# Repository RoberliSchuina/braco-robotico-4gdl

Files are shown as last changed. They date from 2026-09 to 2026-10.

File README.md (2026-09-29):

# Braço Robótico 4 GDL — Sistemas Embarcados (FAESA, 2026/2)

| Entrega | Onde está |
|---|---|
| Lista de componentes | `relatorio/Relatorio_Braco_Robotico.docx` (seção 4) |
| Peças 3D (uma por arquivo) + STL | `STL/01_…11_*.stl` (09 = suporte dos joysticks; 10/11 = garra alternativa em V) — importar cada uma em um projeto do Tinkercad (Importar → STL) |
| Protótipo montado | `STL/montagem_completa.stl`, `imagens/montagem_*.png` |
| Código Arduino IDE | `firmware/braco_robotico/braco_robotico.ino` (placa UNO; libs Servo + EEPROM) |
| Esquema elétrico | `imagens/esquema_eletrico.png` |
| Guia de ligações furo a furo (protoboard) | `Circuito_Braco_Robotico.html` (autocontido; abrir no navegador ou imprimir) |
| Lista de parafusos e fixadores (à parte) | `relatorio/Lista_Parafusos_Fixadores.docx` (também Apêndice C do relatório) |
| Manual de montagem passo a passo | `relatorio/Manual_Montagem.docx` |
| Memória de desenvolvimento/revisão | `CLAUDE.md` |

Impressão (Bambu Lab A1): PLA, bico 0,4 mm, camada 0,20 mm, preenchimento 15 %, 3 paredes, sem suportes, peças já orientadas nos STL (≈ 132 g, ≈ 6,6 h).

**Revisão de 2026-09-24 — estrutura em forquilha e garra horizontal.** Cada elo passou a ter duas chapas laterais simétricas em relação ao plano de rotação da base (03/04 = braço, 05/06 = antebraço), amarradas por uma travessa aparafusada; o servo trabalha entre elas e o lado oposto gira num munhão Ø9 impresso, em cisalhamento duplo. A garra foi para baixo da palma, com as engrenagens de eixo vertical: com o antebraço na horizontal as mandíbulas fecham num plano horizontal e o braço agarra o objeto pelos lados (captura na horizontal). O suporte dos joysticks ganhou berço de cantos em L e rasgos radiais, porque a furação do KY-023 não é padronizada.

**Duas opções de garra.** Opção A (peças 07/08, mandíbula plana) para objetos de faces planas — blocos, caixinhas, cartões. Opção B (peças 10/11, mandíbula em V de 95°) para cilindros e esferas: contato em 4 pontos, o objeto se auto-centra e não rola; como a garra fecha no plano horizontal, o sulco do V fica vertical e pega caneta, pilha ou frasco em pé na mesa. As duas usam a mesma engrenagem e os mesmos parafusos — a troca leva dois minutos e não muda o firmware (ver `imagens/garras.png`).

Regenerar tudo: `python cad/gerar_pecas.py && python cad/gerar_esquema.py && python relatorio/gerar_relatorio.py && python relatorio/gerar_lista_parafusos.py && python relatorio/gerar_manual_montagem.py`\nConferir a mecânica (colisões, engrenagens, envelope e torque): `python cad/verificacao.py`
(requer `pip install trimesh manifold3d shapely numpy matplotlib python-docx`).

Comando: 2 módulos joystick KY-023 (J1 = base/ombro + botão gravar/reproduzir; J2 = garra/cotovelo + botão abre/fecha garra / home). Controle incremental com zona morta; ligar com os joysticks soltos (calibração do centro).

Firmware compilado com `arduino-cli compile --fqbn arduino:avr:uno` em 2026-09-19: 11 650 bytes de flash (36 %), 451 bytes de RAM (22 %), sem avisos.

Verificação (2026-09-24, `python cad/verificacao.py`): 9 malhas estanques conferidas depois de exportadas; varredura booleana do cotovelo (palma encosta na plataforma a 148° → firmware limitado a 40..140°) e do ombro; engrenagens com interpenetração 0,0000 mm² e folga de flanco 0,190 mm; envelope medido no modelo (alcance 186 mm, altura 249 mm); torque do ombro 0,52 kgf·cm em vazio (29 % do travamento) e carga útil ≈ 20 g estendido / ≈ 65 g recolhido. A base **precisa** ser parafusada na tábua de apoio e S3/S4 precisam de extensores de cabo (BOM itens 14 e 15). Limite de operação: com o ombro além de 135° e o cotovelo dobrado, o antebraço desce abaixo do plano da mesa e toca o disco da base.

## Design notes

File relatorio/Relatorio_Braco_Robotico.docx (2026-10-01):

FAESA — CENTRO UNIVERSITÁRIO

Curso de Engenharia da Computação

Disciplina: Sistemas Embarcados — 2026/2

BRAÇO ROBÓTICO DE 4 GRAUS DE LIBERDADE

Projeto, modelagem 3D, impressão (Bambu Lab A1) e firmware em Arduino

Aluno(a): ______________________________________

Professor(a): ___________________________________

Vitória – ES

Setembro de 2026

# Sumário

(pressione F9 para atualizar)

# 1. Objetivo

Construir um braço robótico de 4 graus de liberdade (GDL) utilizando a plataforma de prototipação Arduino, cobrindo todo o ciclo de um sistema embarcado: especificação, projeto mecânico (peças modeladas em 3D e impressas na Bambu Lab A1), projeto eletrônico, firmware em Arduino IDE e testes.

Entregas exigidas pela disciplina:

1. Lista de componentes necessários (seção 4).
2. Modelo 3D de cada peça em arquivos separados, com os arquivos STL individuais para impressão (seções 5 e 6).
3. Desenho do protótipo montado (seção 7).
4. Código-fonte executado no Arduino IDE (seção 9 e Apêndice A).

Requisitos de fabricação: impressora Bambu Lab A1, altura de camada 0,2 mm e densidade de preenchimento 15 %.

# 2. Visão geral da solução

O braço é do tipo articulado (antropomórfico) com quatro juntas acionadas por micro-servos SG90/MG90S: rotação da base (S1), ombro (S2), cotovelo (S3) e garra (S4). As juntas usam o próprio horn (braço) do servo encaixado em um bolso da peça — solução simples, barata e comum em braços didáticos.

Cada elo é uma FORQUILHA: duas chapas de 4 mm, uma de cada lado do plano de rotação da base, ligadas por uma travessa aparafusada. O servo da junta fica entre as duas chapas, com o flange na chapa motriz; do lado oposto, um munhão Ø9 impresso na própria chapa gira em um mancal Ø9,4. Com isso a carga é dividida entre dois apoios (cisalhamento duplo) em vez de pendurar em balanço no eixo do servo, e o centro de massa fica sobre o eixo da base — o conjunto é simétrico e equilibrado, sem o esforço lateral que a versão anterior, em chapa única, impunha ao estriado de nylon do horn.

A garra é de duas engrenagens espelhadas (16 dentes, módulo 1,5): uma acionada pelo servo e a outra girando livre em um pino M3, o que produz abertura simétrica dos dedos. Ela é montada sob a PALMA — uma chapa transversal na ponta do antebraço, que também é a travessa dessa forquilha —, com os eixos das engrenagens ao longo do eixo X do antebraço. Com o antebraço na horizontal esses eixos ficam VERTICAIS e as mandíbulas fecham num plano horizontal: o braço se aproxima de lado e agarra pelas laterais um objeto apoiado na mesa (captura na horizontal), em vez de descer sobre ele com o antebraço apontando para baixo.

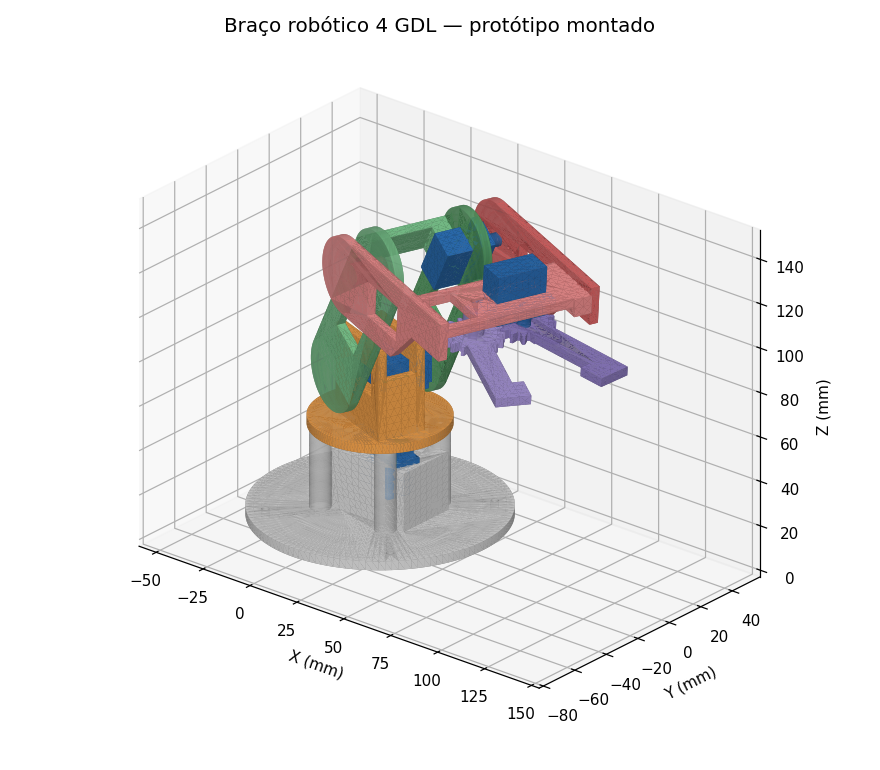
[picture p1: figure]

Figura 1 — Protótipo montado (modelo 3D gerado a partir das peças).

Item | Especificação
Graus de liberdade | 4 (base, ombro, cotovelo, garra)
Atuadores | 4 × micro-servo SG90 (plástico) ou MG90S (metálico, recomendado para ombro e cotovelo)
Controlador | Arduino UNO R3 (ATmega328P, 16 MHz)
Interface de comando | 2 módulos joystick analógico KY-023 (4 eixos + 2 botões: gravar/reproduzir poses, voltar à posição de referência, abrir/fechar garra) + terminal serial
Estrutura dos elos | Forquilha simétrica: 2 chapas de 4 mm por elo (motriz + livre), vão de 37,6 mm no braço e 67,2 mm no antebraço; pivô livre em munhão Ø9 impresso
Comprimento dos elos | Braço 70 mm (ombro→cotovelo); antebraço 62 mm (cotovelo→eixo da garra); dedos 55 mm
Plano de fechamento da garra | Horizontal — engrenagens com eixo vertical quando o antebraço está na horizontal; as mandíbulas ficam 2,8 mm abaixo do eixo do antebraço e 39 mm à frente da ponta das chapas
Alcance horizontal máx. | ≈ 186 mm a partir do eixo da base (ombro em 165°, cotovelo quase esticado); altura do ombro 68,8 mm; altura máxima da ponta dos dedos ≈ 249 mm
Opções de garra | Duas ferramentas intercambiáveis: A (mandíbula plana, objetos prismáticos) e B (mandíbula em V, auto-centrante para cilindros e esferas em pé) — ver seção 5.6
Abertura da garra | 0 mm (mandíbulas encostadas, S4 = 73°) a ≈ 57 mm na raiz / 71 mm nas pontas (S4 = 110°)
Carga útil estimada | ≈ 20 g com o braço estendido (186 mm) e ≈ 65 g com o braço recolhido (vertical), mantendo o ombro em ≤ 50 % do torque de travamento (1,8 kgf·cm a 5 V); ≈ 30 g aceitando 60 %
Alimentação | Fonte chaveada 5 V / 5 A para os servos (mínimo aceitável 3 A — ver seção 8.1); Arduino pelo USB OU pela mesma fonte (nunca os dois ao mesmo tempo); GND comum
Material / massa impressa | PLA, ≈ 137 g no total (11 peças, incluindo o controle de mão dos joysticks)

## 2.1 Envelope de trabalho

Alturas e alcances medidos no modelo 3D montado (referência: mesa de apoio da base, eixo Z; alcance medido a partir do eixo de rotação da base). A altura máxima ocorre com o braço totalmente esticado para cima — ombro a 90° e cotovelo a 180°, dentro dos limites ANG_MIN/ANG_MAX do firmware.

Referência (braço esticado para cima) | Altura (mm)
Topo da torre da base (apoio do servo S1) | 30,0
Eixo do ombro (S2) | 68,8
Eixo do cotovelo (S3), braço vertical | 138,8
Eixo da garra (S4), antebraço vertical (referência geométrica) | 200,8
Ponta dos dedos — altura máxima medida no modelo (cotovelo em 20°) | 249,1

Pose | Ângulos (ombro / cotovelo) | Altura máx. (mm) | Alcance horizontal (mm)
Esticado para cima (altura máxima) | 90° / 20° (limite ANG_MIN do cotovelo) | 249 | 53
Repouso — home | 90° / 90° | 165 | 119
Alcance horizontal máximo | 165° (limite ANG_MAX do ombro) / 20° | 108 | 186

Valores medidos diretamente no modelo 3D (cad/verificacao.py). Como a estrutura agora é simétrica, o centro da garra fica no PLANO do braço — não há mais o deslocamento lateral de ≈ 34 mm da versão em chapa única, e o alcance vale igualmente para os dois lados.

Limite de operação (não é limite de software): com o ombro além de ≈ 135° e o cotovelo dobrado além de ≈ 140°, o antebraço desce abaixo do plano da mesa e chega a tocar o disco da base (interferência medida: 0,1 a 1,5 cm³ nas poses extremas; com o ombro em 165° a garra chega a ≈ 28 mm abaixo da mesa). Não há batente mecânico: ou o operador evita a combinação, ou se reduz ANG_MAX do ombro para 135° no firmware — o que custa ≈ 50 mm de alcance.

# 3. Arquitetura do sistema embarcado

Do ponto de vista de sistemas embarcados, o projeto é um laço de controle em malha aberta a 50 Hz (mesmo período do sinal PWM dos servos, 20 ms). A cada ciclo o firmware lê os sensores (eixos e botões dos joysticks), decide o modo de operação (máquina de estados MANUAL / REPRODUZINDO) e atualiza os atuadores, limitando a velocidade de cada junta para obter movimentos suaves e reduzir picos de corrente. Como o joystick retorna ao centro por mola, o comando é incremental (controle de velocidade): a deflexão do eixo define a taxa de variação do ângulo da junta, com zona morta em torno do centro e curva quadrática para precisão em movimentos finos.

- Entradas: 2 joysticks KY-023 — 4 eixos analógicos (A0–A3, ADC 10 bits) e 2 botões (D2, D4, pull-up interno); porta serial USB (115200 bps).
- Saídas: 4 sinais PWM de servo (D3, D5, D6, D9 — biblioteca Servo.h, pulsos de 500 a 2500 µs), LED de status (D13).
- Memória: até 16 poses gravadas em RAM, com persistência opcional na EEPROM (assinatura de validação); centro de cada eixo do joystick calibrado na partida.
- Segurança: limites mínimo/máximo por junta em software (evitam colisão do antebraço com o braço), partida sequencial dos servos e posição de repouso na inicialização.

# 4. Lista de componentes (BOM)

Preços em reais são estimativas de mercado (2026) para orientar o orçamento; confirmar no momento da compra.

# | Componente | Qtd | Unit. (R$) | Total (R$) | Função / observação

1 | Arduino UNO R3 (ou compatível) + cabo USB A-B | 1 | 80 | 80 | Controlador
2 | Micro-servo MG90S (engrenagem metálica, 180°) | 2 | 28 | 56 | Ombro (S2) e cotovelo (S3) — mesmo torque do SG90 a 5 V (1,8 kgf·cm), mas engrenagens metálicas e rolamento no eixo: resistem a travamentos e ao esforço lateral
3 | Micro-servo SG90 (180°) com kit de horns e parafusos | 2 | 15 | 30 | Base (S1) e garra (S4)
4 | Módulo joystick analógico KY-023 (2 eixos + botão) | 2 | 9 | 18 | Comando manual das 4 juntas (J1: base/ombro; J2: garra/cotovelo)
5 | Cabo jumper fêmea-macho 20 cm (5 vias por joystick) | 10 | 0,4 | 4 | Ligação dos joysticks à protoboard
6 | Fonte chaveada 5 V / 5 A com plug P4 (2,1 mm, centro positivo) | 1 | 50 | 50 | Alimentação dos servos. Dimensionamento na seção 8.1: 1,85 A no pior caso de operação e 2,70 A com os 4 servos travados. Uma fonte de 3 A atende a operação normal, mas fica a 90 % do nominal em travamento
7 | Jack P4 fêmea com borne (adaptador) | 1 | 6 | 6 | Conexão da fonte na protoboard
8 | Capacitor eletrolítico 1000 µF / 16 V (+ 4 cerâmicos 100 nF) | 1 | 4 | 4 | Desacoplamento do barramento dos servos: o eletrolítico cobre o degrau de corrente até a fonte reagir (~100 µs); os cerâmicos, junto a cada conector, cortam o ruído de comutação do motor
9 | Protoboard 400 pontos | 1 | 15 | 15 | Montagem do circuito
10 | Jumpers macho-macho e macho-fêmea (kit 40 + 40) | 1 | 18 | 18 | Ligações
11 | Parafusos e fixadores — ver lista à parte (Apêndice C / Lista_Parafusos_Fixadores.docx) | 1 | 41 | 41 | PA 2,0×8, PA 1,7×6, M3×25 inox + nylock, M3×12 + porcas/arruelas, M3×16, espaçadores
12 | Filamento PLA 1,75 mm (≈ 137 g usados, já com as duas opções de garra) | 1 | 13 | 13 | Custo proporcional do carretel (R$ 90 / kg)
13 | Abraçadeiras de nylon 2,5 × 100 mm + fita dupla-face | 1 | 6 | 6 | Cabos nos elos e no suporte dos joysticks / fixação da base
14 | Base de MDF ou acrílico 200 × 150 × 6 mm (OBRIGATÓRIA) | 1 | 10 | 10 | Fixação da base fixa (4 furos Ø3,4): o disco Ø110 solto tomba com ≈ 15 g na garra em extensão máxima
15 | Cabo extensor de servo, 3 vias, 300 mm (padrão JR/Futaba) | 2 | 4 | 8 | S3 (cotovelo) e S4 (garra): o cabo de fábrica (≈ 250 mm) não chega ao circuito passando pelos elos

Custo total estimado: R$ 359.

Os parafusos, porcas e arruelas estão dimensionados item a item (furo, empilhamento, modelo e material) na lista à parte do Apêndice C, também entregue como documento separado (relatorio/Lista_Parafusos_Fixadores.docx).

Ferramentas: chave Phillips PH0/PH1, chave de boca 5,5 mm, alicate de corte, estilete (rebarbas), ferro de solda (opcional), paquímetro.

# 5. Projeto mecânico e modelagem 3D

## 5.1 Método de modelagem

As peças foram projetadas de forma paramétrica por geometria construtiva de sólidos (CSG) — união e subtração de primitivas (caixas e cilindros), exatamente a lógica de trabalho do Tinkercad (sólidos e furos). O script cad/gerar_pecas.py contém todas as cotas e gera um STL por peça, já na orientação de impressão; a seção 6 descreve como reproduzir/importar cada peça no Tinkercad em um projeto separado.

## 5.2 Peças

Arquivo STL | Peça | Função | Dimensões (mm) | Massa est. | Tempo est.
01_base_fixa.stl | Base fixa | Apoio do braço; abriga o servo S1 (rotação da base) | 110.0 × 110.0 × 40.3 | 40.7 g | 122 min
02_plataforma_giratoria.stl | Plataforma giratória | Fixa no horn de S1; forquilha do ombro (parede motriz de S2 + parede do mancal) | 60.0 × 60.0 × 44.0 | 15.0 g | 45 min
03_braco_motriz.stl | Braço — chapa motriz | Lado acionado do elo superior: horn de S2 e servo S3 | 34.0 × 104.0 × 4.0 | 6.4 g | 19 min
04_braco_livre.stl | Braço — chapa livre | Lado livre do elo superior: munhão do ombro, mancal do cotovelo e travessa | 34.0 × 104.0 × 41.6 | 9.5 g | 29 min
05_antebraco_motriz.stl | Antebraço — chapa motriz | Lado acionado do elo inferior: horn de S3 | 34.0 × 95.0 × 4.0 | 5.6 g | 17 min
06_antebraco_livre.stl | Antebraço — chapa livre + palma | Lado livre do elo inferior e base da garra (servo S4 e pino do dedo livre) | 34.0 × 96.0 × 71.2 | 11.0 g | 33 min
07_garra_dedo_motriz.stl | Dedo motriz da garra | Engrenagem acionada pelo horn de S4 + dedo | 26.4 × 68.2 × 4.0 | 2.3 g | 7 min
08_garra_dedo_livre.stl | Dedo livre da garra | Engrenagem espelhada que gira no pino M3 + dedo | 26.1 × 68.0 × 14.8 | 2.9 g | 9 min
09_suporte_joysticks.stl | Suporte dos joysticks | Controle de mão: berço dos 2 módulos KY-023 (4 rasgos M3 cada) | 160.0 × 100.0 × 9.2 | 38.2 g | 115 min
10_garra_v_dedo_motriz.stl | Dedo motriz da garra em V (opção B) | Alternativa ao 07: mandíbula com entalhe em V que auto-centra cilindros e esferas | 26.4 × 68.2 × 4.0 | 2.3 g | 7 min
11_garra_v_dedo_livre.stl | Dedo livre da garra em V (opção B) | Alternativa ao 08: mesma engrenagem espelhada, com o entalhe em V | 26.1 × 68.0 × 14.8 | 2.9 g | 9 min

Total estimado: ≈ 137 g de PLA e ≈ 6.9 h de impressão (0,2 mm, 15 %). As peças cabem na mesa de 256 × 256 mm da A1 em uma ou duas chapas (o Bambu Studio arranja automaticamente; a base Ø110 e o suporte 160 × 100 não podem ficar lado a lado no mesmo eixo).

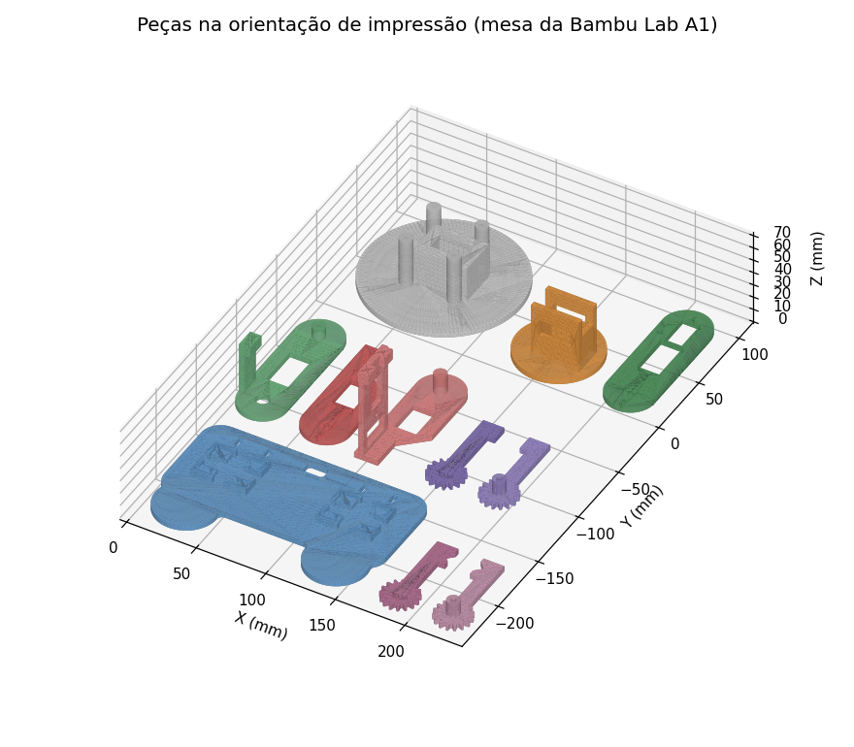
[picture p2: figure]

Figura 2 — As onze peças na orientação de impressão (como devem ficar na mesa): as travessas e a palma são impressas em pé sobre as chapas deitadas.

## 5.3 Interfaces com o servo SG90/MG90S (cotas adotadas)

Elemento | Cota adotada | Justificativa
Rasgo do corpo do servo | 23,2 × 12,6 mm (corpo 22,8 × 12,2) | Folga de 0,2 mm por lado para FDM a 0,2 mm
Furos do flange | Ø1,7 mm, 27,5 mm entre centros | Furo-piloto a 85 % do Ø2,0 do parafuso autoatarraxante do kit do servo
Posição do eixo | Deslocado 5,3 mm do centro do corpo | O eixo do SG90 fica a 6,1 mm da extremidade
Bolso do horn | Cubo Ø9,2; braços em tronco de cone de 9,2 mm (junto ao cubo) a 5,4 mm (ponta); 2,0 mm de profundidade | O braço do horn do SG90 sai tangente ao cubo Ø8 e afina até a ponta — um rasgo reto deixaria o horn sem assentar. Horn de 2 braços (elos), em cruz (plataforma) e simples (garra)
Furo do parafuso central | Ø2,6 mm passante | Parafuso PA 2,0 × 6 + arruela M2 atravessa 2 mm de chapa e o topo do horn e rosqueia ≈ 3 mm no furo cego do eixo (medir a profundidade do furo antes: ver lista de fixadores)
Furos-piloto do horn | Ø1,5 mm | Micro parafusos autoatarraxantes PA 1,7 × 6 (não vêm no kit do servo)
Pino da engrenagem livre | Ø3,4 mm (chapa) / Ø3,4 mm (engrenagem) | Parafuso M3 × 25 inox como eixo + porca autotravante
Engrenagens da garra | 16 dentes, módulo 1,5, Ø primitivo 24 (= distância entre centros), Ø externo 26,4 (addendum 0,8 m); folga de flanco 0,19 mm | Dentes trapezoidais com addendum encurtado: sem interferência de topo; a folga (≈ 1,6° de backlash) absorve a imprecisão do FDM
Munhão / mancal (lado livre) | Munhão Ø9 impresso (8,8 mm no ombro, 14,8 mm no cotovelo) em mancal Ø9,4 passante | Folga diametral de 0,4 mm — gira livre depois de tirar a rebarba. Não leva parafuso: quem prende axialmente é o parafuso central do horn do lado motriz somado à travessa
Travessa do braço / palma do antebraço | 2 furos passantes Ø3,4 na chapa motriz + furo-piloto Ø2,5 × 8 mm no reforço; parafusos M3 × 10 | Amarram as duas chapas de cada elo (fecham a forquilha). Sem elas as chapas abrem sob esforço lateral e o munhão sai do mancal
Espessura das chapas | 4 mm (≈ 20 camadas de 0,2 mm) | Rigidez adequada com 15 % de preenchimento

## 5.4 Análise simplificada de carga

O servo mais solicitado é o ombro (S2). O cálculo é um diagrama de corpo livre feito sobre o próprio modelo 3D (cad/verificacao.py soma massa × braço de alavanca peça por peça, usando o centro de massa de cada malha e 13,4 g por MG90S e 9 g por SG90). Na pior pose — braço e antebraço na horizontal, alcance máximo — dá τ_S2 = 0,52 kgf·cm sem carga (29 % do travamento) e τ_S2 ≈ 0,52 + 0,018·m [kgf·cm, m em gramas] com uma massa m na ponta. A 5 V, SG90 e MG90S entregam o mesmo torque de travamento, ≈ 1,8 kgf·cm (os 2,2 kgf·cm do MG90S são a 6 V).

Um servo de hobby não deve sustentar pose acima de ≈ 50 % do travamento: com 25 g o ombro vai a 54 % e com 50 g a 79 % (aquece e perde posição). Daí a carga útil de ≈ 20 g em extensão máxima — ou ≈ 30 g aceitando 60 % do travamento em movimentos curtos. Com o braço recolhido (vertical) o braço de alavanca cai para o antebraço apenas e a carga útil sobe para ≈ 65 g. O cotovelo (S3) fica em 39 % mesmo com 50 g e a garra tem força de sobra (≈ 3,6 N de travamento na mandíbula).

Comparação com a versão anterior, em chapa única: duplicar as chapas levou a massa móvel de ≈ 39 g para ≈ 59 g e o torque em vazio de 0,39 para 0,52 kgf·cm, custando ≈ 5 g de carga útil. Em troca, cada junta passou a trabalhar em cisalhamento duplo (dois apoios em vez de um balanço), o esforço lateral sobre o estriado de nylon do horn praticamente desapareceu e o centro de massa ficou sobre o eixo da base — o que também alivia S1. As janelas nas quatro chapas e na palma foram dimensionadas para recuperar parte dessa massa. O MG90S é indicado nas juntas 2 e 3 não pelo torque, mas pelas engrenagens metálicas e pelo rolamento do eixo. Ponto fraco remanescente: o conjunto girante pendura no eixo de S1 sem mancal — por isso a base tem quatro colunas de encosto a 0,5 mm da plataforma, que limitam o balanço sem travar o giro.

## 5.5 Suporte dos joysticks (controle de mão)

Os dois módulos KY-023 são montados em uma placa impressa no formato de controle de videogame (160 × 100 × 9,2 mm, arquivo 09_suporte_joysticks.stl), inspirada nos suportes de MDF cortados a laser. Joystick 1 (esquerda) comanda base e ombro; joystick 2 (direita), garra e cotovelo — mesma lógica de um controle de videogame.

Fixação — por que não é por furo: a placa do KY-023 mede 34 × 26 mm (valor confirmado nas fichas do fabricante e de distribuidores), mas NENHUM datasheet publica a distância entre os furos Ø3, e ela varia de fabricante para fabricante; além disso o gimbal do joystick (≈ 22 × 22 mm) encosta nos furos do lado estreito em vários clones. Por isso o suporte não depende dessa cota:

- Berço de 4 cantos em L: posiciona o módulo pela BORDA da placa (envelope 34,6 × 26,6 mm), com assento de 3 mm que afasta as soldas da chapa e lábio de 2,2 mm que trava a placa lateralmente.
- 4 rasgos radiais 3,4 × 11,4 mm: o parafuso M3 corre 8 mm na direção radial, de modo que a mesma peça aceita qualquer furação simétrica entre ≈ 21,5 × 15,4 mm e ≈ 34,5 × 24,6 mm (o nominal adotado é 28 × 20 mm). Medir a placa com paquímetro só é necessário se ela estiver fora dessa faixa — aí basta alterar JOY_FUROS no script.
- Parafusos M3 × 12 + arruela ampla Ø9 + porca: 2 a 4 por módulo, conforme os furos acessíveis na placa. Se o gimbal cobrir dois deles, os cantos do berço já impedem o módulo de sair de posição.

Acima de cada módulo há dois rasgos para abraçadeira de nylon, que prendem o chicote de 5 fios (barra de pinos voltada para cima), e no topo um rasgo para pendurar o controle.

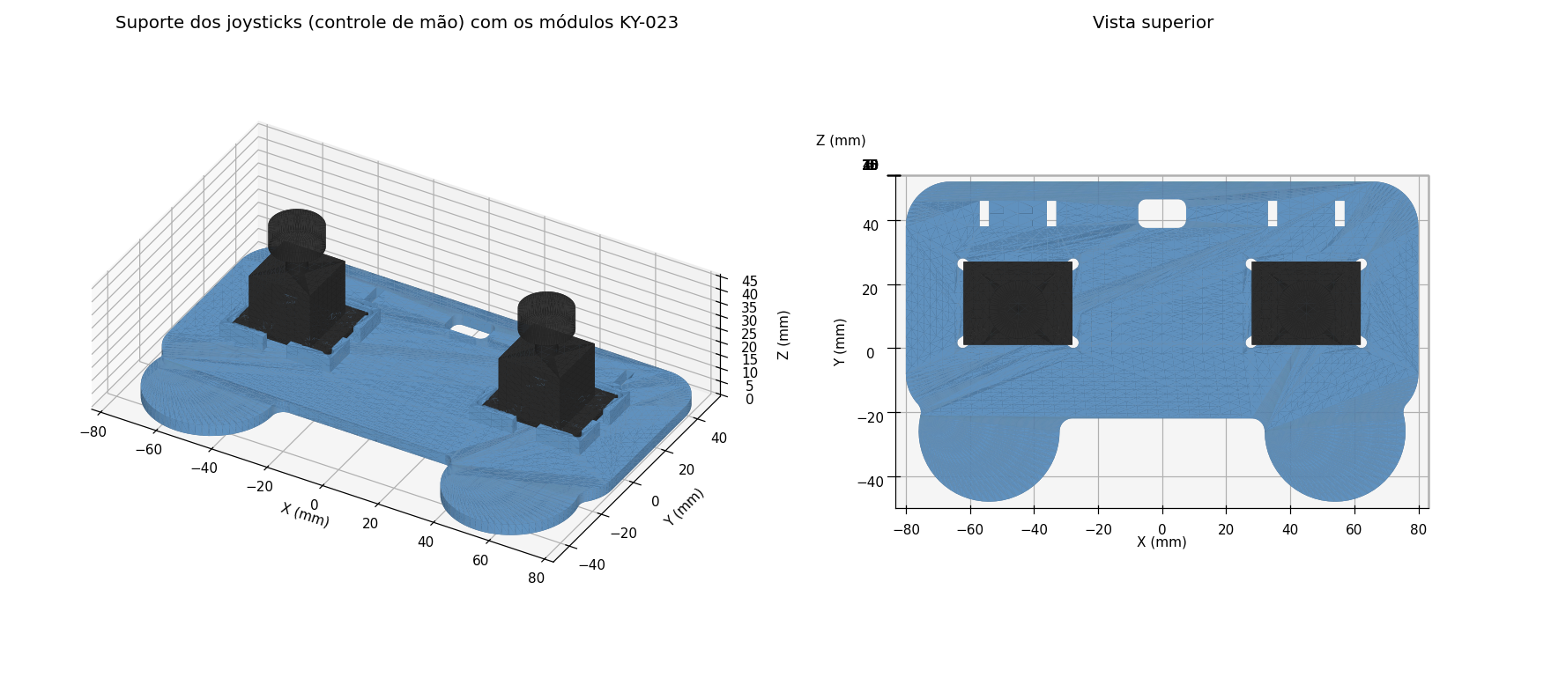
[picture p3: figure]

Figura 3 — Suporte dos joysticks: berço de cantos em L e rasgos radiais, com os dois módulos KY-023 posicionados.

## 5.6 Duas opções de garra (ferramenta intercambiável)

A garra é a interface com o objeto, e nenhuma geometria serve para tudo. O projeto entrega dois pares de dedos que usam a MESMA engrenagem, o mesmo bolso de horn, o mesmo pino M3 e a mesma distância entre centros — ou seja, são troca direta, sem alterar antebraço, palma, servo ou firmware:

- Opção A — mandíbula plana (07 e 08): faces retas de 10 × 12 mm. Contato em 2 pontos, ideal para objetos de faces planas e paralelas: blocos, caixinhas, cartões, peças prismáticas. É a garra montada nas figuras deste relatório.
- Opção B — mandíbula em V (10 e 11): faces de 10 × 17 mm com entalhe em V de ≈ 95° (apex 5 mm dentro da face, abertura 11 mm). Contato em 4 pontos: o objeto se auto-centra e não rola nem escapa. Como a garra fecha no plano horizontal, o sulco do V fica VERTICAL — é a opção para pegar cilindros e esferas em pé sobre a mesa: canetas, marcadores, pilhas, tubos de ensaio, frascos, bolinhas.

Capacidade medida no modelo (maior cilindro em pé que as duas mandíbulas tocam ao mesmo tempo, em função do ângulo do servo da garra; 75° = dedos paralelos, 110° = ANG_MAX):

Ângulo de S4 | 75° (dedos paralelos) | 80° | 90° | 100° | 110° (aberta)
Opção A — plana | Ø 4 mm | Ø 13 mm | Ø 29 mm | Ø 44 mm | Ø 58 mm
Opção B — em V | Ø 10 mm | Ø 15 mm | Ø 28 mm | Ø 41 mm | Ø 53 mm

Perto do fechamento a diferença é grande: com os dedos quase paralelos a opção A só consegue prender uma lâmina de 4 mm, enquanto o V já abraça um cilindro de 10 mm. Na abertura máxima as duas são equivalentes (o V “gasta” 5 mm de cada mandíbula). Em ambas, o ângulo em que as mandíbulas se tocam é o mesmo (73° no servo), então GARRA_FECHADA e ANG_MIN[3] do firmware não mudam com a troca.

Troca da garra (2 minutos): soltar o parafuso central do horn de S4 e o parafuso M3 × 25 do dedo livre, retirar os dois dedos, montar o outro par na mesma ordem da seção 7.1 (S4 em 75°, dedos paralelos) e reapertar. O horn continua no dedo motriz de cada par — quem imprimir as duas opções pode deixar um horn em cada uma e a troca fica ainda mais rápida (o kit do servo traz vários horns).

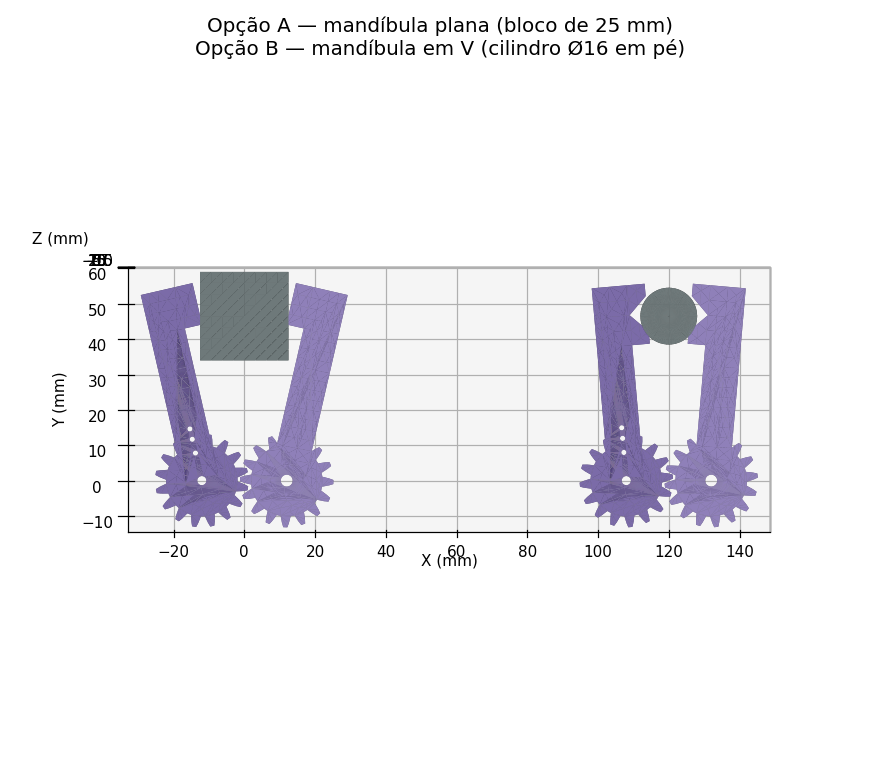
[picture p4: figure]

Figura 4 — As duas opções de garra vistas pelo eixo das engrenagens: à esquerda a mandíbula plana com um bloco de 25 mm; à direita a mandíbula em V com um cilindro Ø16 em pé.

# 6. Modelagem no Tinkercad e geração dos STL

## 6.1 Importar os STL prontos (um projeto por peça)

5. Acesse https://www.tinkercad.com/dashboard e clique em Criar → Projeto 3D.
6. Clique em Importar (canto superior direito) → selecione STL/01_base_fixa.stl → unidade: milímetros → escala 100 %.
7. Renomeie o projeto (ex.: “Braço 4GDL – 01 Base fixa”). Repita para as outras oito peças, cada uma em um projeto separado.
8. Para o protótipo montado, importe STL/montagem_completa.stl em um décimo projeto (visualização).
9. Exportar: Exportar → .STL (o Tinkercad gera um STL individual por projeto). Esses arquivos vão para o Bambu Studio.

## 6.2 Receita para modelar cada peça com primitivas do Tinkercad

Caso se deseje construir as peças do zero no Tinkercad (sólidos = formas; furos = formas marcadas como “Furo”; alinhar e agrupar), as cotas abaixo reproduzem o modelo. Origem: centro da peça; Z para cima.

01 Base fixa

- Sólidos: Cilindro Ø110 × 4; Caixa 38,6 × 28 × 27 (torre) apoiada em z=3, centro em x=+5,3; 4 Cilindros Ø9 × 36,3 (colunas de encosto) em raio 24,5 (45°, 135°, 225°, 315°), de z=4 a z=40,3.
- Furos: Caixa 28 × 18 × 28 (cavidade, centro x=+5,3, de z=−1 a 27); Caixa 8 × 60 × 2 (canal do cabo, sob a base, x −4..4, y 0..60); Caixa 23,2 × 12,6 (rasgo do servo na tampa, centro x=+5,3); 2 Cilindros Ø1,7 em x=−8,45 e x=+19,05; 4 Cilindros Ø3,4 em raio 47 (45°, 135°, 225°, 315°).

02 Plataforma giratória

- Sólidos: Cilindro Ø60 × 4; DUAS Caixas 34,6 × 4 × 41 (paredes da forquilha: uma em y 4..8, outra em y −14..−10; z 3..44; centro x=+5,3); 2 Caixas 4 × 14,5 × 27 (nervuras que ligam as duas paredes, em x −12..−8 e 18,6..22,6; y −10..4,5; z 3..30).
- Furos: bolso em cruz na face inferior (Cilindro Ø9,2 × 2 + 4 braços de 14 mm em tronco de cone Ø9,2→Ø5,4, profundidade 2); Cilindro Ø2,6 passante no centro; 8 Cilindros Ø1,5 (±7,5 e ±11 nos dois eixos); rasgo 23,2 × 12,6 na parede motriz (centro x=+5,3, z=28) + 2 Cilindros Ø1,7 em x=−8,45 e +19,05 (z=28); Cilindro Ø9,4 passante na parede livre em (0; z=28) — é o mancal do munhão do braço.

03 Braço — chapa motriz

- Sólidos: Caixa 34 × 4 × 70 + 2 Cilindros Ø34 × 4 (eixo Y) em z=0 e z=70 (chapa no plano XZ).
- Furos: janela 16 × 30 (z 22..52); bolso duplo na face interna (Cilindro Ø9,2 × 2 + 2 braços de 16,5 mm em tronco de cone Ø9,2→Ø5,4); Cilindro Ø2,6 passante em z=0; 4 furos Ø1,5 em z=±8 e ±12; rasgo 12,6 (x) × 23,2 (z) centrado em (0; 64,7) [eixo do servo em z=70]; furos Ø1,7 em z=50,95 e z=78,45; 2 furos Ø3,4 em (−13; 59) e (−13; 67) para os parafusos da travessa.

04 Braço — chapa livre

- Sólidos: mesma silhueta da chapa motriz; Cilindro Ø9 × 9,8 saindo da face interna em z=0 (munhão do ombro); Caixa 4 × 38,6 × 14 (travessa: x −17..−13, y −1..37,6, z 56..70); Caixa 8 × 8 × 14 (reforço dos furos-piloto, x −17..−9, y 29,6..37,6).
- Furos: janela 16 × 30 (z 22..52); Cilindro Ø9,4 passante em z=70 (mancal do cotovelo); 2 furos-piloto Ø2,5 × 8,4 na face livre do reforço, em (−13; 59) e (−13; 67).

05 Antebraço — chapa motriz

- Sólidos: Cilindro Ø34 × 4 em z=0; Caixa 34 × 4 × 40; a partir de z=40 a borda inferior recua em diagonal até x=0 em z=56 e segue reta até a ponta (z=78), para deixar as mandíbulas livres.
- Furos: janela 16 × 24 (z 20..44); bolso duplo + Ø2,6 + 4 furos Ø1,5 como no braço; 2 furos Ø3,4 em (−10; 54) e (−10; 74) para os parafusos da palma.

06 Antebraço — chapa livre + palma

- Sólidos: mesma silhueta da chapa motriz; Cilindro Ø9 × 15,8 na face interna em z=0 (munhão do cotovelo); Caixa 4 × 68,2 × 30 (PALMA: x −14..−10, y −1..67,2, z 48..78); 2 Caixas 8 × 8 × 10 (reforços dos furos-piloto na ponta da palma).
- Furos: janela 16 × 24; na palma, rasgo 23,2 × 12,6 do servo S4 (eixo em y=45,6 medido da face interna, z=62; corpo ao longo de −y) + 2 Cilindros Ø1,7 em y=26,55 e y=54,05; Cilindro Ø3,4 em (y=21,6; z=62) — pino do dedo livre; janela 13 × 22 na palma (y 3..16, z 52..74); 2 furos-piloto Ø2,5 × 8,4 em (−10; 54) e (−10; 74).

07 Dedo motriz

- Sólidos: Engrenagem (Geradores de forma → Gear): 16 dentes, módulo 1,5, Ø externo 26,4 (addendum 1,2 mm), altura 4; Caixa 10 × 55 × 4 (haste, y 0..55); Caixa 10 × 12 × 4 (mandíbula, x 0..10, y 43..55).
- Furos: bolso simples na face superior (Cilindro Ø9,2 × 2 + 1 braço de 18 mm em tronco de cone Ø9,2→Ø5,4); Cilindro Ø2,6 passante; 3 furos Ø1,5 em y=8, 12 e 15.

08 Dedo livre

- Espelho do dedo motriz (mandíbula em x −10..0), sem bolso do horn; engrenagem girada 11,25° (meio dente).
- Sólido extra: Cilindro Ø9 × 10,8 sobre a engrenagem (espaçador). Furo: Cilindro Ø3,4 passante.

10 e 11 — Dedos da garra em V (opção B)

- Iguais aos dedos 07 e 08, com duas diferenças: a mandíbula vai de y=38 a y=55 (em vez de y=43..55) e recebe um furo em forma de cunha.
- Furo: Triângulo (prisma de 4 mm de altura) com vértices (±10,5; 41), (±10,5; 52) e (±5; 46,5) — apex 5 mm dentro da face de trabalho, abertura de 11 mm. No Tinkercad: forma “Wedge”/“Roof” girada, ou um cilindro de 3 lados achatado, marcado como Furo.

09 Suporte dos joysticks

- Sólidos: Caixa 160 × 74 × 4 com cantos R14 (corpo, y −22..52); 2 Cilindros Ø44 × 4 em (±54; −26) (empunhaduras); por módulo (centros em (±45; 14)), 4 cantos em L alinhados com a borda da placa (envelope 34,6 × 26,6): assento 11 × 8 × 3 mm sob cada canto + 2 paredinhas de 2,5 mm de espessura e 5,2 mm de altura.
- Furos: 4 rasgos radiais por módulo (Caixa 3,4 × 8 com pontas redondas, apontando do centro do módulo para o furo nominal em ±14; ±10); 4 Caixas 3 × 8 em (±33..36; 38..46) e (±54..57; 38..46) (abraçadeiras); rasgo de pendurar 15 × 9 com pontas redondas centrado em (0; 42).

# 7. Protótipo montado

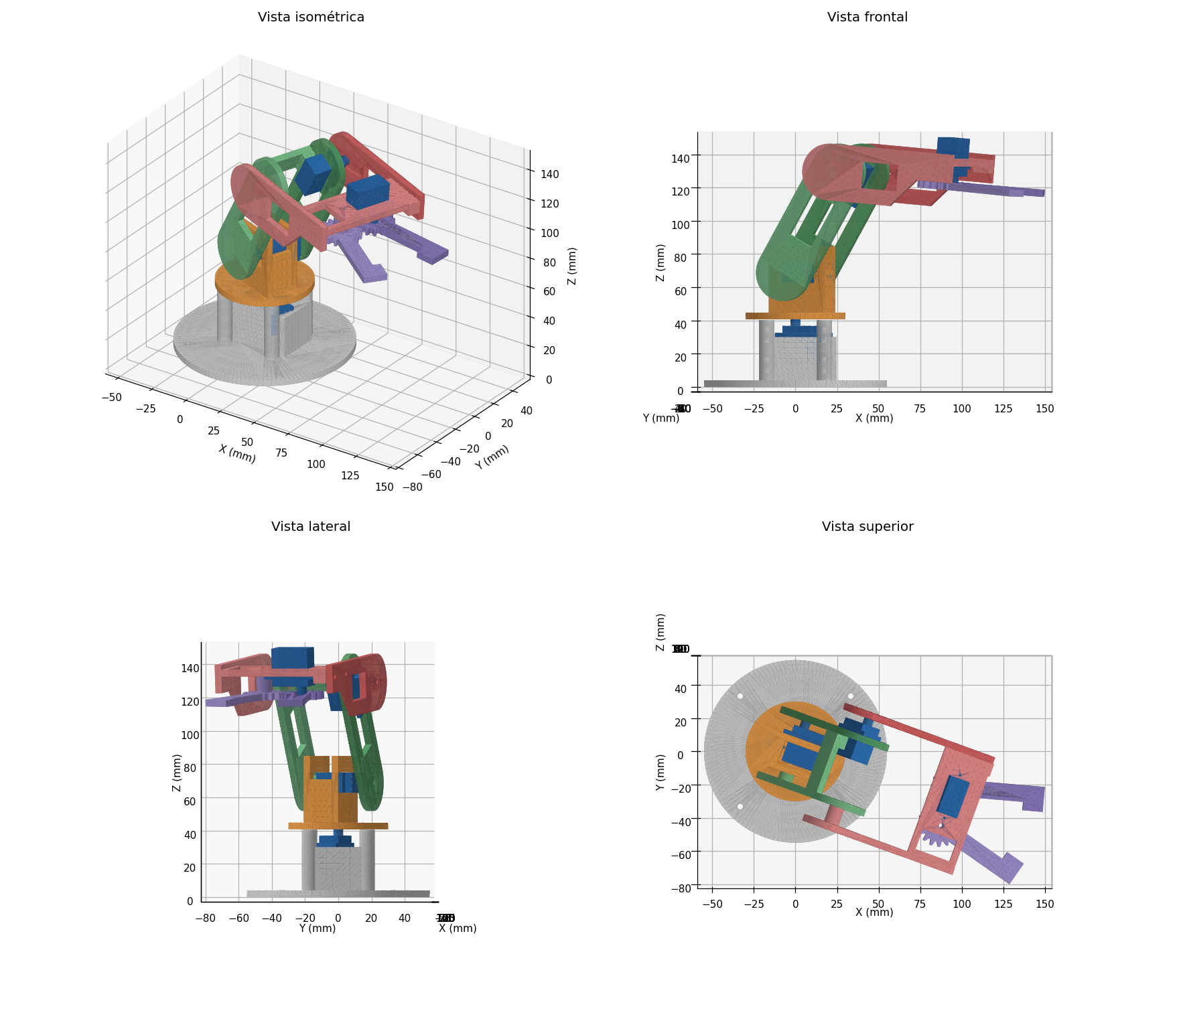
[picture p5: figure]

Figura 5 — Vistas isométrica, frontal, lateral e superior do protótipo montado (servos em azul).

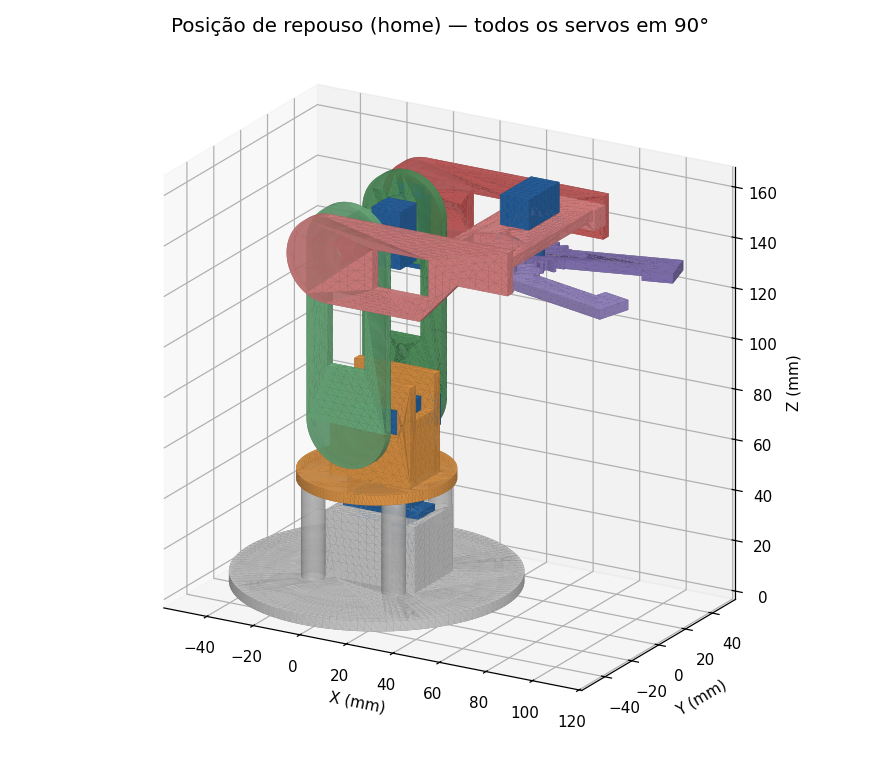
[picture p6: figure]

Figura 6 — Posição de repouso (home): todos os servos em 90°.

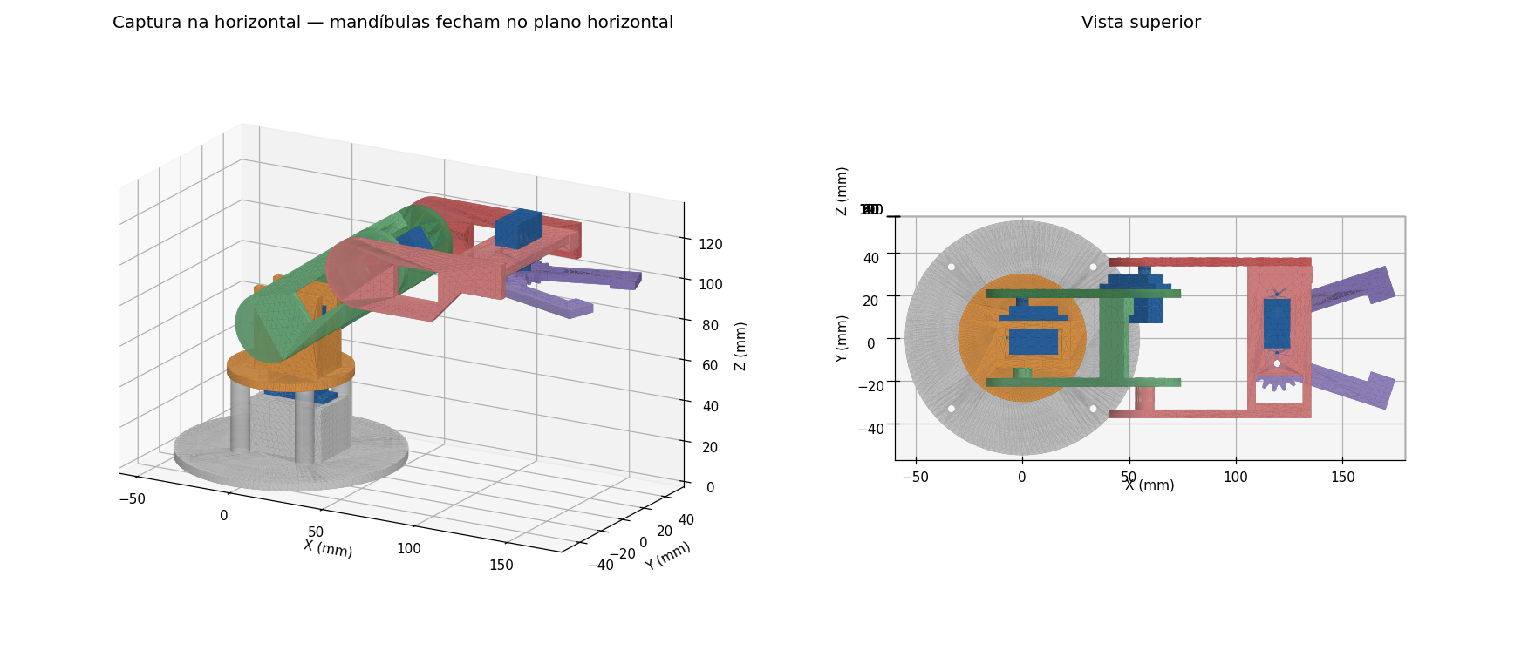
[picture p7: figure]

Figura 7 — Captura na horizontal: com o antebraço na horizontal, os eixos das engrenagens ficam verticais e as mandíbulas fecham no plano horizontal (vista superior à direita).

## 7.1 Sequência de montagem

10. Remover rebarbas; testar o encaixe de cada servo nos rasgos (deve entrar justo, sem forçar) e de cada munhão Ø9 no seu mancal Ø9,4 (deve girar livre; se prender, lixar o munhão, nunca o furo). Rosquear um parafuso PA 2,0 no furo cego do eixo de cada servo, sem peça, e medir com paquímetro quanto entra: define o comprimento do parafuso central (lista de fixadores, item 1b).
11. Base fixa: parafusar o disco na tábua de apoio (4 × M3 × 16 nos furos Ø3,4 — obrigatório, o braço estendido tomba sem isso); encaixar S1 por cima na torre (flange apoiado na tampa) e fixar com 2 parafusos PA 2,0 × 8 (do kit do servo).
12. Ligar o Arduino, carregar o firmware e enviar 's 0 90', 's 1 90', 's 2 90', 's 3 75' para centralizar os servos antes de montar os horns.
13. Plataforma: colocar o horn em cruz no bolso inferior (deve assentar no fundo; 4 micro parafusos PA 1,7 × 6), encaixar no eixo de S1 com a plataforma a 0,5 mm das colunas de encosto e fixar com o parafuso central (PA 2,0 × 6 + arruela M2). O estriado do eixo tem ≈ 21 dentes (≈ 17° por dente): escolher a posição mais próxima do alinhamento e corrigir o resto na calibração.
14. Fixar S2 na parede MOTRIZ da plataforma (a de y = 4..8): o corpo atravessa a parede para dentro da forquilha e o flange fica na face externa. Conferir que a extremidade do corpo do servo não encosta na parede livre (folga de projeto: 2,1 mm).
15. Braço: montar o horn duplo no bolso da chapa motriz (03). Encaixar primeiro a chapa LIVRE (04) — o munhão entra no mancal da parede livre —, depois a chapa motriz no eixo de S2, na vertical, e apertar o parafuso central. Fechar a forquilha aparafusando a travessa da chapa livre na chapa motriz (2 × M3 × 10, por fora da chapa motriz).
16. Fixar S3 na chapa motriz do braço (flange na face externa, corpo para dentro da forquilha).
17. Antebraço: montar o horn duplo no bolso da chapa motriz (05). Encaixar a chapa LIVRE (06, a que traz a palma) pelo munhão no mancal da chapa livre do braço; encaixar a chapa motriz no eixo de S3 a 90° do braço e apertar o parafuso central. Fechar a forquilha aparafusando a palma na chapa motriz (2 × M3 × 10).
18. Garra: aparafusar S4 na palma pelo lado de baixo (flange contra a face interna da palma, corpo atravessando para cima; 2 × PA 2,0 × 8) ANTES de montar as engrenagens — um dos furos do flange fica sob a engrenagem motriz.
19. Dedo livre: parafuso M3 × 25 de cima para baixo pela palma, arruela de nylon, dedo (espaçador Ø9 contra a palma), arruela e porca autotravante — apertar só até girar livre.
20. Dedo motriz: horn simples no bolso; com S4 em 75° encaixar a engrenagem já engrenada com o dedo livre e os dois dedos paralelos; parafuso central. Conferir que as duas mandíbulas fecham no plano horizontal quando o antebraço está na horizontal.
21. Ligar os extensores de 300 mm em S3 e S4 e passar os cabos ao longo dos elos (abraçadeiras), com uma laçada de folga em cada junta; S2 e S1 alcançam o circuito com o cabo de fábrica.
22. Garra alternativa (opção B, peças 10 e 11): se quiser trocar o par de dedos, repetir os dois passos anteriores com os dedos em V — mesma ordem, mesmo parafuso M3 × 25 e mesmo ângulo de montagem (S4 em 75°, dedos paralelos).
23. Controle de mão: assentar cada módulo KY-023 no berço (a placa encosta nos 4 cantos em L), parafusar com M3 × 12 + arruela ampla + porca nos rasgos radiais que coincidirem com os furos da placa (2 são suficientes se o gimbal cobrir os outros), com a barra de pinos voltada para cima; prender os chicotes nos rasgos com abraçadeiras e ligar à protoboard conforme o esquema.

# 8. Projeto eletrônico

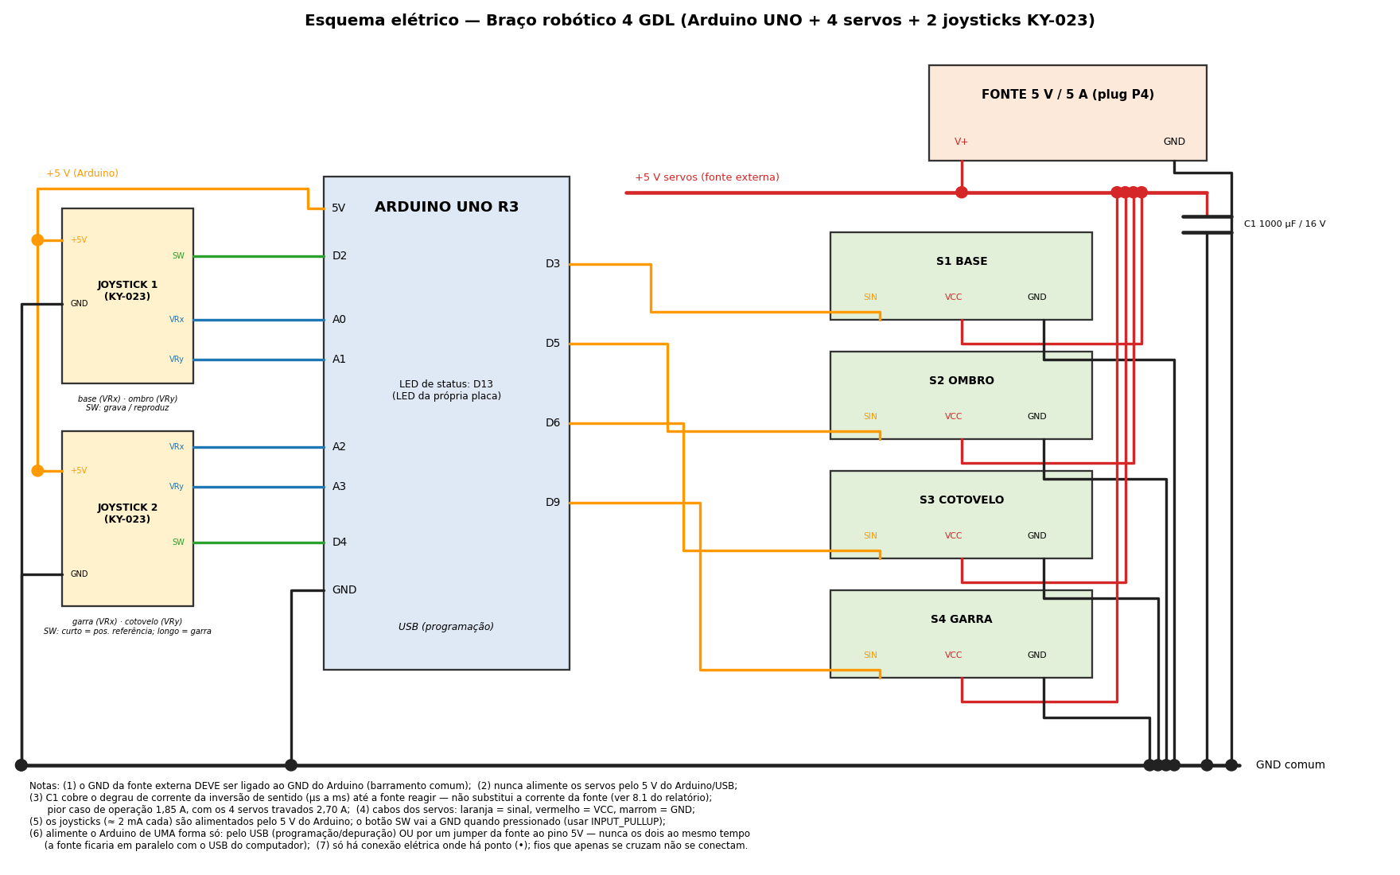
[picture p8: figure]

Figura 8 — Esquema elétrico de ligação.

Sinal | Pino Arduino | Componente | Observação
PWM servo base (S1) | D3 | SG90 — fio laranja | Servo.h, 600–2400 µs
PWM servo ombro (S2) | D5 | MG90S — fio laranja
PWM servo cotovelo (S3) | D6 | MG90S — fio laranja
PWM servo garra (S4) | D9 | SG90 — fio laranja
Joystick 1 — VRx / VRy | A0 / A1 | KY-023 (base / ombro) | +5 V e GND do Arduino
Joystick 1 — SW | D2 | Botão do joystick (para GND) | INPUT_PULLUP; curto = grava pose, longo = reproduz/para
Joystick 2 — VRx / VRy | A2 / A3 | KY-023 (garra / cotovelo) | +5 V e GND do Arduino
Joystick 2 — SW | D4 | Botão do joystick (para GND) | INPUT_PULLUP; curto = volta à posição de referência, longo = abre/fecha garra
LED de status | D13 | LED da placa | Aceso = manual; piscando = reproduzindo
+5 V servos | — | Fonte 5 V / 5 A + C1 1000 µF | NUNCA pelo 5 V do Arduino
GND | GND | Comum a fonte, servos, pots e Arduino | Obrigatório

## 8.1 Dimensionamento da fonte de alimentação

O datasheet do MG90S (TowerPro) publica apenas massa, dimensões, torque de travamento (1,8 kgf·cm a 4,8 V e 2,2 kgf·cm a 6 V), velocidade (0,1 s/60° a 4,8 V), faixa de tensão (4,8–6,0 V) e banda morta (5 µs) — não há nenhuma especificação de corrente. O dimensionamento foi feito, portanto, a partir de medições publicadas por fornecedores (a 5 V: 10 mA em repouso, 120–250 mA girando em vazio e 700 mA com o rotor travado) combinadas com o modelo de motor CC de escovas, no qual a corrente cresce linearmente com o torque exigido:

I(T) = I₀ + (I_travado − I₀) · (T / T_travado)

Aplicando as frações de torque calculadas na seção 5.4 (corpo livre com as massas reais das malhas), chega-se ao consumo por junta e aos cenários de operação abaixo. O script cad/verificacao_eletrica.py reproduz a tabela.

Junta (servo) | Torque exigido | Corrente movendo | Com 25 g na garra
S1 base (SG90) | ≈ 5 % do travamento (eixo vertical) | 272 mA | 286 mA
S2 ombro (MG90S) | 29 % em vazio / 54 % com 25 g | 380 mA | 493 mA
S3 cotovelo (MG90S) | 18 % em vazio / 28 % com 25 g | 331 mA | 376 mA
S4 garra (SG90) | travamento parcial ao apertar o objeto | 295 mA | 520 mA

Cenário | Corrente total | % de uma fonte de 3 A
Repouso — 4 servos parados sustentando o braço | 0,47 A | 16 %
Manual (joystick) — 1 eixo movendo, 3 sustentando | 0,72 A | 24 %
Manual com objeto de 25 g, garra apertando | 1,21 A | 40 %
Reprodução — 4 eixos simultâneos, sem carga | 1,28 A | 43 %
Reprodução — 4 eixos simultâneos + 25 g | 1,68 A | 56 %
Reprodução — 4 eixos simultâneos + 50 g (carga útil máx.) | 1,85 A | 62 %
Falha — os 4 servos travados ao mesmo tempo | 2,70 A | 90 %
Pico de milissegundos — 1 servo invertendo o sentido | ≈ 2,6 A | —

Em operação normal o pior caso é 1,85 A. O consumo só se aproxima de 3 A na condição de falha em que os quatro servos travam simultaneamente (braço preso, garra fechando sobre um objeto rígido além do limite) — situação em que uma fonte de 3 A trabalharia a 90 % do valor nominal, sem margem para a queda de tensão típica dessas placas sob carga plena. Por isso especificou-se 5 V / 5 A: mantém 85 % de margem mesmo nessa falha, sem custo relevante. Uma fonte de 3 A de boa procedência atende ao projeto; uma de 2 A, não.

Capacitor e capacidade de corrente resolvem problemas diferentes. Quando um servo inverte o sentido em plena velocidade, a força contra-eletromotriz soma-se à tensão aplicada e a corrente chega a cerca de 1,4 A por alguns milissegundos; nenhuma fonte chaveada responde em microssegundos, e é o capacitor que entrega esse degrau localmente. Mas a energia armazenada é pequena: C1 = 1000 µF, admitindo 0,2 V de queda, guarda 0,2 mC — suficiente para sustentar um déficit de 2 A por apenas 100 µs. Para cobrir um travamento de 1 s seriam necessários cerca de 2 F (2 000 000 µF). O capacitor elimina, portanto, a queda rápida de tensão (que provoca reset do Arduino, quando alimentado pela mesma fonte, e tremor nos servos), mas não substitui a capacidade de corrente da fonte, e o inverso também é verdadeiro: uma fonte de 10 A sem capacitor continuaria a afundar no transitório por causa da indutância dos cabos.

Requisitos da fonte: 5 V ± 5 % chaveada, ≥ 4 A (5 A recomendado), regulação de carga melhor que 5 %, ondulação < 100 mV pico a pico e proteção contra sobrecorrente. Não elevar para 6 V em busca dos 2,2 kgf·cm: a corrente de travamento subiria para ≈ 0,85 A por servo (3,4 A no conjunto) e toda a análise de torque da seção 5.4 foi feita para 1,8 kgf·cm a 5 V.

## 8.2 Modelo para simulação (EveryCircuit)

Simuladores analógicos como o EveryCircuit não possuem microcontrolador, servo nem módulo joystick em sua biblioteca — apenas fontes, resistores, reativos, chaves, amplificadores operacionais, diodos, transistores, portas lógicas, latches, CIs e medidores. O esquema da Figura 8, portanto, não pode ser digitado nesse tipo de ferramenta. O que se simula é o subsistema de potência, que é justamente onde estão as tensões e correntes de interesse: cada servo é substituído por uma chave em série com um resistor de valor R = 5 V / I, com I retirado da tabela da seção 8.1.

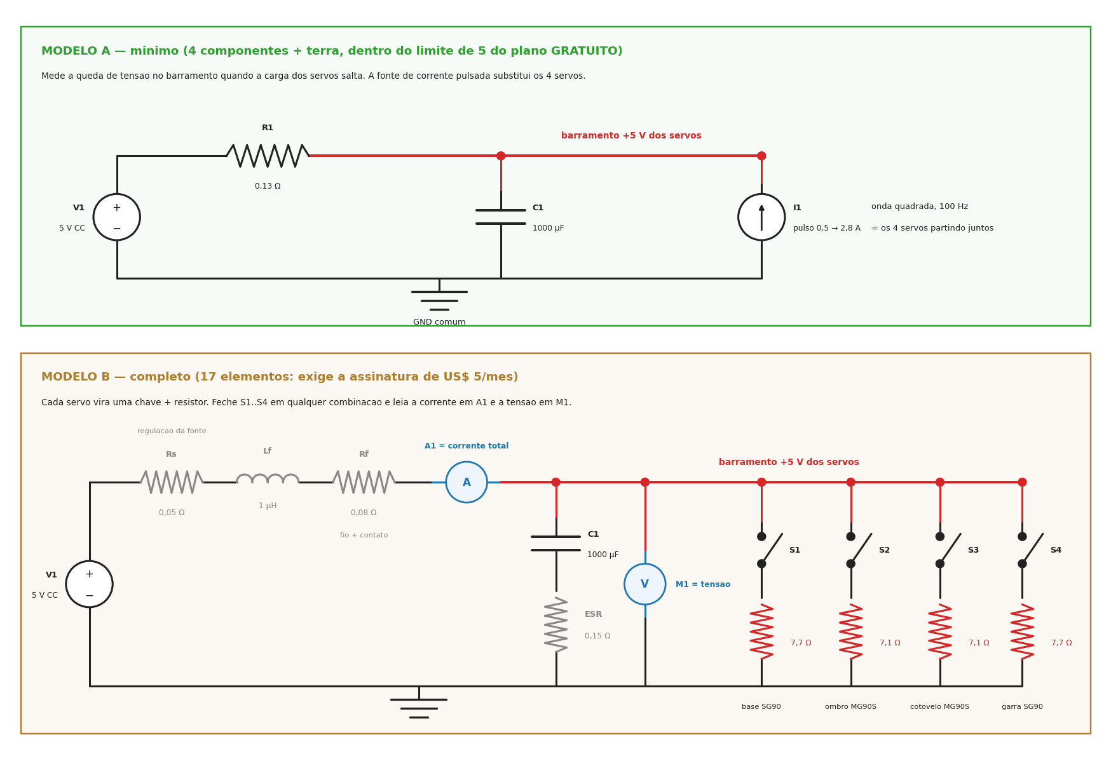
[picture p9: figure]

Figura 9 — Modelo equivalente do barramento de 5 V para simulação. O modelo A usa quatro componentes e cabe no limite gratuito do EveryCircuit; o modelo B detalha os quatro servos.

Elemento | Valor | O que representa
V1 — fonte de tensão CC | 5 V | Fonte chaveada ideal
Rs — resistor | 0,05 Ω (fonte de 5 A) ou 0,083 Ω (3 A) | Regulação de carga da fonte (5 % na corrente nominal)
Lf — indutor | 1 µH | Indutância do par de fios da fonte
Rf — resistor | 0,08 Ω | 0,5 m de 22 AWG (ida e volta) + um contato de protoboard
C1 — capacitor | 1000 µF | Capacitor de desacoplamento do projeto
ESR — resistor | 0,15 Ω | Resistência série equivalente do eletrolítico
S1–S4 — chaves | — | Ligam e desligam cada servo
Resistores de carga | 7,7 / 7,1 / 7,1 / 7,7 Ω | Servos travados (base, ombro, cotovelo, garra)
Resistores de carga (alt.) | 18,4 / 13,2 / 15,1 / 16,9 Ω | Mesmos servos em movimento

Resultados esperados em regime permanente, com os quatro servos ligados: 1,24 A e 4,84 V no barramento com os servos em movimento; 2,53 A e 4,66 V com os quatro travados. Trocando Rs para 0,083 Ω (fonte de 3 A), os mesmos casos dão 4,80 V e 4,59 V — o segundo já bem abaixo do mínimo de 4,8 V do datasheet, o que confirma a escolha da fonte de 5 A feita na seção 8.1.

No transitório, aplicando um degrau de 'em movimento' para 'travado', a tensão mínima do barramento é 4,64 V com C1 e apenas 2,29 V sem ele — neste modelo, que ignora de propósito a capacitância de saída da própria fonte para isolar o efeito de C1. A queda instantânea é dominada pela ESR e não pela capacitância, razão pela qual dois eletrolíticos de 470 µF em paralelo (ESR pela metade) seguram o transitório melhor do que um único de 1000 µF. O script cad/gerar_esquema_everycircuit.py gera a Figura 9 e recalcula todos esses valores.

## 8.3 Fiação

Fiação: o orçamento de queda de tensão é de apenas 200 mV (5,0 V da fonte contra os 4,8 V mínimos do datasheet). Meio metro de jumper 22 AWG conduzindo 2 A já consome 106 mV (ida e volta); recomenda-se 20 AWG ou mais grosso no trecho fonte → protoboard. O elo mais frágil é o contato da protoboard: cada ponto suporta cerca de 1 A, de modo que a entrada da fonte deve ser feita por dois furos em paralelo (ou por um borne parafusado) e os quatro servos devem ser distribuídos ao longo da trilha, nunca no mesmo furo.

# 9. Firmware (Arduino IDE)

Arquivo: firmware/braco_robotico/braco_robotico.ino. Bibliotecas: Servo.h e EEPROM.h (nativas da IDE). Placa: Arduino UNO.

## 9.1 Estrutura

- Configuração: tabelas de pinos, limites (ANG_MIN/ANG_MAX) e posição de referência (POS_REF) por junta.
- Laço de controle (50 Hz): lê os 4 eixos dos joysticks; fora da zona morta (±60 counts) calcula um incremento de ângulo proporcional ao quadrado da deflexão (até VEL_JOY = 2 °/passo = 100 °/s), soma ao alvo da junta dentro dos limites e aproxima a posição atual do alvo a no máximo velMax graus por passo (rampa de velocidade).
- Máquina de estados: MANUAL (joysticks) ↔ REPRODUZINDO (percorre as poses gravadas com pausa de 0,5 s em cada uma). Ao parar a reprodução o alvo assume a posição atual, e os joysticks continuam de onde o braço parou, sem saltos.
- Botões dos joysticks: SW1 curto = grava pose (LED pisca 3×), SW1 longo ≥ 0,8 s = inicia/para reprodução; SW2 curto = volta à posição de referência (POS_REF, 90° em todas as juntas), SW2 longo = abre/fecha a garra. Debounce por tempo; estrutura Botao reutilizada para os dois.
- Serial: comandos de uma letra para calibração e depuração (p, g, l, r, m, h, a, j, e, c, v<n>, s <junta> <ângulo>); 'j' recalibra o centro dos joysticks.
- EEPROM: poses salvas com assinatura 0xB4A1 e carregadas automaticamente na partida.

## 9.2 Fluxo de execução

24. setup(): inicializa serial, botões e LED; anexa os servos um a um (150 ms entre eles) já na posição de referência; calibra o centro dos 4 eixos (16 leituras, joysticks soltos); carrega poses da EEPROM.
25. loop(): trata serial e botões a cada iteração; a cada 20 ms executa o passo do modo atual (leJoysticks + avancaParaAlvo, ou passoReproducao) e atualiza o LED.
26. avancaParaAlvo(): para cada junta, move no máximo velMax graus, satura nos limites e escreve nos servos.

## 9.3 Testes e calibração

27. Sem as peças montadas, carregar o firmware e usar 's <j> <ang>' para verificar o sentido e a faixa de cada servo.
28. Montar e ajustar ANG_MIN/ANG_MAX de cada junta. O firmware sai com o cotovelo limitado a 40..140° (simétrico, porque o sentido do servo só se conhece agora). Cotovelo: descobrir com 's 2 <ang>' em qual sentido o antebraço dobra sobre o braço; desse lado NÃO passar de 145° (a palma encosta na parede da plataforma a 148°, medido por varredura booleana); do lado 'esticado' pode-se abrir até 20°, ganhando alcance. Ombro: com o ombro além de ≈ 135° e o cotovelo dobrado, o antebraço desce abaixo do plano da mesa e toca o disco da base — evitar a combinação ou reduzir ANG_MAX[1] para 135.
29. Calibrar a garra: com o horn montado a 75° (dedos paralelos, vão de 4 mm), reduzir o ângulo de 1 em 1 grau ('s 3 74', 's 3 73'...) até as mandíbulas encostarem; anotar esse ângulo em ANG_MIN[3] e usar ≈ 2° acima dele em GARRA_FECHADA (nunca abaixo: o servo fica em travamento). 's 3 110' deve abrir ≈ 57 mm na raiz das mandíbulas.
30. Verificar o sentido de cada eixo do joystick (inclinar para a direita deve girar a base para a direita etc.); inverter pelo vetor SENTIDO[] se necessário.
31. Com os joysticks soltos, o braço deve ficar imóvel; se houver deriva, aumentar ZONA_MORTA ou recalibrar com 'j'.
32. Validar o modo manual (suavidade, ausência de tremor) e o ciclo gravar → reproduzir com 4–6 poses (ex.: pegar e soltar um objeto de 20 g usando SW2 longo para a garra).
33. Medir a corrente da fonte durante o movimento (multímetro em série na linha +5 V dos servos): esperam-se ≈ 0,5 A em repouso e 1,2–1,9 A com os quatro eixos em movimento sob carga (seção 8.1). Leitura muito acima disso indica servo travado contra um batente; se o Arduino reiniciar, verificar o GND comum e o capacitor C1.
34. Medir a tensão no barramento dos servos com o braço em esforço: não deve cair abaixo de 4,8 V. Se cair, a fonte está subdimensionada ou os fios de alimentação são finos demais.

# 10. Parâmetros de impressão — Bambu Lab A1

Parâmetro | Valor | Observação
Impressora / bico | Bambu Lab A1, bico 0,4 mm | Volume 256 × 256 × 256 mm
Material | PLA (Bambu PLA Basic ou similar) | 220 °C bico / 60 °C mesa (mesa PEI texturizada)
Perfil de processo | 0.20 mm Standard @BBL A1 | Altura de camada 0,20 mm; 1ª camada 0,20 mm
Preenchimento | 15 %, padrão Grid ou Gyroid | Requisito do projeto
Paredes / topo / base | 3 perímetros (1,2 mm) / 4 camadas / 3 camadas | Rigidez das chapas de 4 mm
Suportes | Desativados | Maior ponte: 23 mm (teto do rasgo do servo na plataforma e na palma); maior balanço: 2,6 mm. As travessas e a palma são impressas EM PÉ sobre a chapa (paredes verticais), e os munhões Ø9 saem na vertical — nenhuma dessas peças precisa de suporte
Adesão | Nenhuma (brim de 3 mm opcional na plataforma) | Mesa limpa com álcool isopropílico
Compensação de furos (X-Y hole compensation) | 0,10 mm se os furos ficarem justos | Furos Ø1,5–1,9 tendem a encolher em FDM
Orientação | Conforme os STL (face plana para baixo) | Ver Figura 2 e tabela da seção 5.2
Fluxo de trabalho | STL → Bambu Studio (ou MakerWorld) → fatiar → enviar por Wi-Fi/SD

# 11. Cronograma sugerido e riscos

Semana | Atividade | Entrega
1 | Compra dos componentes; revisão dos modelos no Tinkercad | Projetos Tinkercad + STL
2 | Impressão das 11 peças (≈ 7 h, incluindo as duas opções de garra) e ajustes de encaixe (munhões e bolsos) | Peças impressas
3 | Montagem mecânica + circuito na protoboard | Protótipo montado
4 | Firmware, calibração dos limites e testes de pega | Vídeo de demonstração + relatório final

- Risco — furos apertados: usar compensação de furos de 0,1 mm ou alargar com broca de 1,8/3,5 mm.
- Risco — servo sem torque: verificar tensão da fonte sob carga; trocar SG90 por MG90S no ombro/cotovelo.
- Risco — horn folgado no bolso: aplicar uma gota de cola quente no bolso além dos parafusos.
- Risco — reset do Arduino: GND comum, capacitor C1 e nunca alimentar servos pela USB.
- Risco — joystick com deriva (braço se move sozinho): ligar o sistema com os joysticks soltos (calibração do centro), aumentar ZONA_MORTA ou usar o comando 'j'.

# 12. Referências

- Tinkercad — https://www.tinkercad.com/dashboard
- Bambu Lab A1 — especificações técnicas e Bambu Studio — https://bambulab.com/en/a1
- Arduino — referência da biblioteca Servo — https://www.arduino.cc/reference/en/libraries/servo/
- TowerPro — folha de dados do micro-servo SG90 / MG90S (corpo 22,8 × 12,2 mm; torque de travamento 1,8 kgf·cm a 4,8 V para ambos; MG90S 2,2 kgf·cm a 6 V; pulso 500–2400 µs).
- Trimesh + Manifold (modelagem CSG em Python) — https://trimesh.org
- NISE, N. S. Engenharia de Sistemas de Controle. 7. ed. LTC, 2017 (fundamentos de atuadores e controle).

# Apêndice A — Código-fonte completo (braco_robotico.ino)

/*

* ============================================================================

* BRAÇO ROBÓTICO 4 GDL — Sistemas Embarcados (FAESA – Engenharia da Computação)

* Plataforma: Arduino UNO R3 (ATmega328P) — Arduino IDE 2.x

* Atuadores : 4 micro-servos SG90/MG90S (base, ombro, cotovelo, garra)

* Comando : 2 módulos joystick analógico KY-023 (2 eixos + botão cada)

* ----------------------------------------------------------------------------

* MAPA DE PINOS

* D3 -> sinal servo S1 (base) JOYSTICK 1: VRx -> A0 (base)

* D5 -> sinal servo S2 (ombro) VRy -> A1 (ombro)

* D6 -> sinal servo S3 (cotovelo) SW -> D2 (gravar / reproduzir)

* D9 -> sinal servo S4 (garra) JOYSTICK 2: VRx -> A2 (garra)

* D13 -> LED de status (LED da placa) VRy -> A3 (cotovelo)

* SW -> D4 (volta a referencia; longo = garra)

* Joysticks: +5V e GND do Arduino. Servos: fonte externa 5 V / 5 A (GND comum!)

* ----------------------------------------------------------------------------

* CONTROLE

* O joystick volta sozinho ao centro, por isso o comando é INCREMENTAL (velocidade):

* inclinar o eixo move a junta na direção correspondente, tanto mais rápido quanto

* maior a inclinação (curva quadrática para precisão perto do centro); soltar = para.

* O centro de cada eixo é calibrado na partida (não toque nos joysticks ao ligar).

* MODOS

* MANUAL : joysticks comandam as juntas.

* REPRODUZINDO: percorre ciclicamente as poses gravadas (até 16).

* BOTÕES

* SW1 curto = grava a pose atual SW1 longo (> 0,8 s) = inicia/para a reprodução

* SW2 curto = VOLTA À POSIÇÃO DE REFERÊNCIA (POS_REF, todas as juntas em 90°)

* SW2 longo (> 0,8 s) = abre/fecha a garra

* (garra: 74° ≈ fechada, 110° = aberta — valores nominais, calibrar; os dedos se tocam em ~72,5°)

* A garra é montada sob a palma, com as engrenagens de eixo vertical: com o antebraço na horizontal as

* mandíbulas fecham num PLANO HORIZONTAL (o braço agarra o objeto pelos lados, apoiado na mesa).

* Há dois pares de dedos intercambiáveis (mandíbula plana e mandíbula em V, auto-centrante para

* cilindros e esferas em pé). Os dois têm o mesmo ângulo de toque, então nada muda aqui na troca.

* COMANDOS SERIAIS (115200 bps) — calibração e depuração:

* p imprime posições g grava pose l limpa poses r reproduz/para

* m manual (para) h pos. de referência a abre/fecha garra j recalibra centro dos joysticks

* e salva poses na EEPROM c carrega da EEPROM v <n> velocidade máx. (1..10 °/passo)

* s <j> <ang> move a junta j (0..3) para <ang> graus

* ============================================================================

*/

#include <Servo.h>

#include <EEPROM.h>

// ------------------------------------------------------------ configuração

const uint8_t N_JUNTAS = 4;

const uint8_t PIN_SW1 = 2; // botão do joystick 1

const uint8_t PIN_SW2 = 4; // botão do joystick 2

const uint8_t PIN_LED = 13;

const uint16_t PERIODO_MS = 20; // período do laço de controle (50 Hz = período do PWM dos servos)

const uint16_t TOQUE_LONGO_MS = 800;

const uint8_t MAX_POSES = 16;

const uint16_t EEPROM_MAGIC = 0xB4A1; // assinatura para validar dados na EEPROM

const int ZONA_MORTA = 60; // counts do ADC (~6 %) ignorados em torno do centro do joystick

const float VEL_JOY = 2.0f; // graus por passo com o joystick no fim de curso (2 °/20 ms = 100 °/s)

// limites mecânicos (graus do servo) — AJUSTE NA CALIBRAÇÃO (seção 9 do relatório). Valores nominais:

// base : 5..175 — nunca 0/180 (extremos da faixa de pulso = batente interno do servo, zumbido e aquecimento)

// ombro : 15..165 — com o ombro > ~45° e o antebraço apontando para baixo a garra passa do plano da mesa:

// não há batente mecânico, o operador (ou a base elevada) evita

// cotovelo : 40..140 — dobrando o antebraço sobre o braço, a PALMA da garra encosta na parede da plataforma

// a partir de 148° (varredura booleana; no braço em si só toca a 160°). Como o sentido do servo só

// se conhece na calibração, o limite é simétrico: depois de calibrar, o lado "esticado" pode ir a

// 20° e o lado "dobrado" NUNCA deve passar de 145°

// garra : 72..110 — as mandíbulas se tocam em ~72,5° (horn montado a 75° = dedos paralelos); abaixo disso

// o servo fica em travamento (stall) permanente

// base ombro cotovelo garra

const uint8_t ANG_MIN[N_JUNTAS] = { 5, 15, 40, 72 };

const uint8_t ANG_MAX[N_JUNTAS] = { 175, 165, 140, 110 };

// POSIÇÃO DE REFERÊNCIA (pose de repouso, também chamada de "home"): é onde o braço é inicializado no

// setup() e para onde ele volta sempre que se aperta o botão do joystick 2 (toque curto) ou se envia 'h'.

// Todas as juntas em 90°, o meio da faixa útil de cada servo, porque:

// base 90° : centro do curso (5..175) -> mesmo alcance para os dois lados

// ombro 90° : braço na VERTICAL -> braço de alavanca ~0 e torque mínimo no servo mais carregado

// cotovelo 90° : antebraço perpendicular ao braço -> longe dos 148° em que a palma encosta na

// plataforma e longe do fim de curso esticado

// garra 90° : meio curso (74..110), ~30 mm de vão -> não aperta o objeto nem fecha contra si mesma

// É também a pose em que os horns dos servos são encaixados na montagem (manual de montagem, etapa 7):

// mudar estes valores obriga a remontar os horns, não é só mexer no código.

// Nesta pose o modelo mede 165 mm de altura e 119 mm de alcance horizontal (cad/mapa_angulos.json).

const uint8_t POS_REF[N_JUNTAS] = { 90, 90, 90, 90 };

const uint8_t PIN_SERVO[N_JUNTAS] = { 3, 5, 6, 9 };

const uint8_t PIN_EIXO[N_JUNTAS] = { A0, A1, A3, A2 }; // J1-VRx, J1-VRy, J2-VRy, J2-VRx

const int8_t SENTIDO[N_JUNTAS] = { 1, 1, 1, 1 }; // troque para -1 para inverter o sentido de um eixo

const char* NOME[N_JUNTAS] = { "base", "ombro", "cotovelo", "garra" };

const uint8_t GARRA = 3;

const uint8_t GARRA_FECHADA = 74, GARRA_ABERTA = 110; // 74 ≈ 2 mm de vão; 110 ≈ 57 mm. Calibrar (seção 9.3)

// ------------------------------------------------------------ estado

enum Modo : uint8_t { MANUAL, REPRODUZINDO };

Servo servo[N_JUNTAS];

float posAtual[N_JUNTAS]; // posição comandada (graus, com casas decimais para suavizar)

float alvo[N_JUNTAS]; // posição desejada

int centro[N_JUNTAS]; // leitura do ADC com o joystick em repouso (calibrada na partida)

float velMax = 3.0f; // graus por passo (3 °/20 ms = 150 °/s) — usado em referência / reprodução / comando s

Modo modo = MANUAL;

uint8_t poses[MAX_POSES][N_JUNTAS];

uint8_t nPoses = 0;

uint8_t poseAtual = 0;

uint32_t tPausaPose = 0; // pausa entre poses na reprodução

// botões dos joysticks (definidos antes das funções: o Arduino IDE gera os protótipos no topo do arquivo)

struct Botao {

uint8_t pino;

bool pressionado;

bool longoDisparado;

uint32_t tInicio;

};

Botao sw1 = { PIN_SW1, false, false, 0 }, sw2 = { PIN_SW2, false, false, 0 };

// ------------------------------------------------------------ utilidades

static float limita(float v, float lo, float hi) { return v < lo ? lo : (v > hi ? hi : v); }

void aplicaServos() {

for (uint8_t j = 0; j < N_JUNTAS; j++) servo[j].write((int)(posAtual[j] + 0.5f));

}

// aproxima posAtual de alvo respeitando a velocidade máxima -> movimentos suaves, sem "trancos"

bool avancaParaAlvo() {

bool chegou = true;

for (uint8_t j = 0; j < N_JUNTAS; j++) {

float d = alvo[j] - posAtual[j];

if (fabs(d) > velMax) { posAtual[j] += (d > 0 ? velMax : -velMax); chegou = false; }

else { posAtual[j] = alvo[j]; }

posAtual[j] = limita(posAtual[j], ANG_MIN[j], ANG_MAX[j]);

}

aplicaServos();

return chegou;

}

void calibraJoysticks() {

for (uint8_t j = 0; j < N_JUNTAS; j++) {

long soma = 0;

for (uint8_t k = 0; k < 16; k++) { soma += analogRead(PIN_EIXO[j]); delay(2); }

centro[j] = soma / 16;

}

Serial.print(F("Centro dos joysticks:"));

for (uint8_t j = 0; j < N_JUNTAS; j++) { Serial.print(' '); Serial.print(centro[j]); }

Serial.println();

}

// controle incremental: deflexão do joystick -> incremento de ângulo por passo

void leJoysticks() {

for (uint8_t j = 0; j < N_JUNTAS; j++) {

int d = analogRead(PIN_EIXO[j]) - centro[j]; // -512..+511 em torno do centro

if (abs(d) < ZONA_MORTA) continue; // dentro da zona morta: não move

float n = (abs(d) - ZONA_MORTA) / (512.0f - ZONA_MORTA); // 0..1

n = limita(n, 0.0f, 1.0f);

float inc = VEL_JOY * n * n * (d > 0 ? 1 : -1) * SENTIDO[j]; // curva quadrática: fino perto do centro

alvo[j] = limita(alvo[j] + inc, ANG_MIN[j], ANG_MAX[j]);

}

}

void imprimePosicoes() {

Serial.print(F("modo=")); Serial.print(modo == MANUAL ? F("MANUAL") : F("REPRODUZINDO"));

Serial.print(F(" poses=")); Serial.print(nPoses);

for (uint8_t j = 0; j < N_JUNTAS; j++) {

Serial.print(F(" ")); Serial.print(NOME[j]); Serial.print('='); Serial.print((int)posAtual[j]);

}

Serial.println();

}

void gravaPose() {

if (nPoses >= MAX_POSES) { Serial.println(F("Memoria de poses cheia (16).")); return; }

for (uint8_t j = 0; j < N_JUNTAS; j++) poses[nPoses][j] = (uint8_t)posAtual[j];

nPoses++;

Serial.print(F("Pose gravada #")); Serial.println(nPoses);

for (uint8_t i = 0; i < 3; i++) { digitalWrite(PIN_LED, HIGH); delay(60); digitalWrite(PIN_LED, LOW); delay(60); }

}

void iniciaReproducao() {

if (nPoses == 0) { Serial.println(F("Nenhuma pose gravada.")); return; }

modo = REPRODUZINDO; poseAtual = 0; tPausaPose = 0;

Serial.println(F("Reproduzindo sequencia (SW1 longo, 'r' ou 'm' para parar)."));

}

void pararReproducao() {

modo = MANUAL;

for (uint8_t j = 0; j < N_JUNTAS; j++) alvo[j] = posAtual[j]; // joysticks continuam de onde parou

Serial.println(F("Reproducao parada. Modo MANUAL."));

}

// volta todas as juntas para a posição de referência, no mesmo ritmo controlado da reprodução

// (velMax graus por passo). limita() protege contra uma POS_REF editada fora dos limites calibrados.

void vaiParaReferencia() {

modo = MANUAL;

for (uint8_t j = 0; j < N_JUNTAS; j++) alvo[j] = limita(POS_REF[j], ANG_MIN[j], ANG_MAX[j]);

Serial.print(F("Voltando para a posicao de referencia:"));

for (uint8_t j = 0; j < N_JUNTAS; j++) { Serial.print(' '); Serial.print((int)alvo[j]); }

Serial.println(F(" graus."));

}

void alternaGarra() {

bool aberta = alvo[GARRA] > (GARRA_FECHADA + GARRA_ABERTA) / 2;

alvo[GARRA] = aberta ? GARRA_FECHADA : GARRA_ABERTA;

Serial.println(aberta ? F("Garra: fechando") : F("Garra: abrindo"));

}

// ------------------------------------------------------------ EEPROM (poses persistentes)

void salvaEEPROM() {

int a = 0;

EEPROM.put(a, EEPROM_MAGIC); a += sizeof(EEPROM_MAGIC);

EEPROM.put(a, nPoses); a += sizeof(nPoses);

for (uint8_t i = 0; i < nPoses; i++)

for (uint8_t j = 0; j < N_JUNTAS; j++) EEPROM.update(a++, poses[i][j]);

Serial.print(F("Salvo na EEPROM: ")); Serial.print(nPoses); Serial.println(F(" poses."));

}

bool carregaEEPROM() {

int a = 0; uint16_t magic; uint8_t n;

EEPROM.get(a, magic); a += sizeof(magic);

if (magic != EEPROM_MAGIC) return false;

EEPROM.get(a, n); a += sizeof(n);

if (n > MAX_POSES) return false;

for (uint8_t i = 0; i < n; i++)

for (uint8_t j = 0; j < N_JUNTAS; j++) poses[i][j] = EEPROM.read(a++);

nPoses = n;

Serial.print(F("EEPROM: ")); Serial.print(nPoses); Serial.println(F(" poses carregadas."));

return true;

}

// ------------------------------------------------------------ botões (toque curto / longo, com debounce)

// retorna 1 = toque curto, 2 = toque longo, 0 = nada

uint8_t leBotao(Botao &b) {

bool agora = (digitalRead(b.pino) == LOW);

if (agora && !b.pressionado) { b.pressionado = true; b.tInicio = millis(); b.longoDisparado = false; }

if (agora && b.pressionado && !b.longoDisparado && millis() - b.tInicio >= TOQUE_LONGO_MS) {

b.longoDisparado = true; return 2;

}

if (!agora && b.pressionado) {

b.pressionado = false;

if (!b.longoDisparado && millis() - b.tInicio > 30) return 1;

}

return 0;

}

void trataBotoes() {

uint8_t e1 = leBotao(sw1), e2 = leBotao(sw2);

if (e1 == 2) { if (modo == REPRODUZINDO) pararReproducao(); else iniciaReproducao(); }

else if (e1 == 1) { if (modo == REPRODUZINDO) pararReproducao(); else gravaPose(); }

// toque curto no botão do joystick 2 = volta à posição de referência (vaiParaReferencia() já devolve

// o modo para MANUAL, por isso não precisa de pararReproducao() antes)

if (e2 == 1) vaiParaReferencia();

else if (e2 == 2) { if (modo == REPRODUZINDO) pararReproducao(); alternaGarra(); }

}

// ------------------------------------------------------------ comandos seriais

void trataSerial() {

if (!Serial.available()) return;

String linha = Serial.readStringUntil('\n'); linha.trim();

if (linha.length() == 0) return;

char c = linha.charAt(0);

switch (c) {

case 'p': imprimePosicoes(); break;

case 'g': gravaPose(); break;

case 'l': nPoses = 0; if (modo == REPRODUZINDO) pararReproducao(); Serial.println(F("Poses apagadas.")); break;

case 'r': if (modo == REPRODUZINDO) pararReproducao(); else iniciaReproducao(); break;

case 'm': if (modo == REPRODUZINDO) pararReproducao(); else Serial.println(F("Modo MANUAL (joysticks).")); break;

case 'h': vaiParaReferencia(); break;

case 'a': alternaGarra(); break;

case 'j': calibraJoysticks(); break;

case 'e': salvaEEPROM(); break;

case 'c': if (!carregaEEPROM()) Serial.println(F("EEPROM sem dados validos.")); break;

case 'v': { int v = linha.substring(1).toInt(); if (v >= 1 && v <= 10) velMax = v; Serial.print(F("velMax=")); Serial.println(velMax); } break;

case 's': { // s <junta> <angulo>

int j = linha.substring(1).toInt();

int sp = linha.indexOf(' ', 2);

int ang = (sp > 0) ? linha.substring(sp + 1).toInt() : -1;

if (j >= 0 && j < N_JUNTAS && ang >= 0 && ang <= 180) {

if (modo == REPRODUZINDO) pararReproducao();

alvo[j] = limita(ang, ANG_MIN[j], ANG_MAX[j]);

Serial.print(NOME[j]); Serial.print(F(" -> ")); Serial.println((int)alvo[j]);

} else Serial.println(F("Uso: s <junta 0..3> <angulo 0..180>"));

} break;

default: Serial.println(F("Comandos: p g l r m h a j e c v<n> s<j> <ang>"));

}

}

// ------------------------------------------------------------ reprodução de sequência

void passoReproducao() {

if (tPausaPose) { // pausa de 500 ms em cada pose

if (millis() - tPausaPose < 500) return;

tPausaPose = 0;

poseAtual = (poseAtual + 1) % nPoses;

}

if (nPoses == 0) { pararReproducao(); return; }

// limita a pose aos limites atuais: uma pose gravada antes de recalibrar ANG_MIN/ANG_MAX (ou lida de uma

// EEPROM antiga) deixaria alvo fora da faixa e avancaParaAlvo() nunca "chegaria" -> reprodução congelada

for (uint8_t j = 0; j < N_JUNTAS; j++) alvo[j] = limita(poses[poseAtual][j], ANG_MIN[j], ANG_MAX[j]);

if (avancaParaAlvo()) tPausaPose = millis();

}

// ------------------------------------------------------------ setup / loop

void setup() {

Serial.begin(115200);

Serial.setTimeout(50);

pinMode(PIN_SW1, INPUT_PULLUP);

pinMode(PIN_SW2, INPUT_PULLUP);

pinMode(PIN_LED, OUTPUT);

for (uint8_t j = 0; j < N_JUNTAS; j++) {

posAtual[j] = alvo[j] = POS_REF[j];

servo[j].attach(PIN_SERVO[j], 600, 2400); // dentro da faixa do SG90/MG90S (500-2400 µs); 2500 forçava o batente

servo[j].write(POS_REF[j]);

delay(150); // liga os servos em sequência (pico de corrente menor)

}

calibraJoysticks(); // joysticks devem estar soltos (centro)

carregaEEPROM();

Serial.println(F("\nBraco robotico 4 GDL (joysticks) pronto. Digite '?' para ajuda."));

imprimePosicoes();

}

void loop() {

static uint32_t tUltimo = 0;

trataSerial();

trataBotoes();

uint32_t agora = millis();

if (agora - tUltimo < PERIODO_MS) return; // laço de controle a 50 Hz

// se um bloqueio longo (ex.: os delay() de gravaPose) atrasou vários períodos, ressincroniza em vez de

// executar os ciclos perdidos em rajada (que somaria vários incrementos do joystick num único salto)

tUltimo = (agora - tUltimo > 3UL * PERIODO_MS) ? agora : tUltimo + PERIODO_MS;

if (modo == REPRODUZINDO) {

passoReproducao();

digitalWrite(PIN_LED, (millis() / 250) % 2); // LED piscando = reproduzindo

return;

}

leJoysticks(); // MANUAL: joysticks incrementam o alvo

avancaParaAlvo();

digitalWrite(PIN_LED, HIGH);

}

# Apêndice B — Estrutura de arquivos do projeto

Braço Mecânico/

├── Detalhes.txt enunciado do projeto

├── README.md guia rápido

├── CLAUDE.md memória de desenvolvimento e revisão (decisões, cotas, pendências)

├── cad/

│ ├── gerar_pecas.py modelagem paramétrica (gera STL, montagem e imagens)

│ ├── verificacao.py varreduras de colisão, engrenagens, envelope e torque

│ ├── gerar_esquema.py esquema elétrico

│ └── pecas_info.json dimensões/massa/tempo de cada peça

├── STL/

│ ├── 01_base_fixa.stl … 11_garra_v_dedo_livre.stl uma peça por arquivo (orientação de impressão)

│ └── montagem_completa.stl protótipo montado

├── imagens/ montagem_*.png, pecas_impressao.png, suporte_joysticks.png, esquema_eletrico.png

├── firmware/braco_robotico/braco_robotico.ino código para o Arduino IDE

└── relatorio/

├── gerar_relatorio.py gera este documento

├── parafusos.py dados da lista de fixadores (usada aqui e no documento à parte)

├── gerar_lista_parafusos.py gera Lista_Parafusos_Fixadores.docx

├── Lista_Parafusos_Fixadores.docx

└── Relatorio_Braco_Robotico.docx

# Apêndice C — Lista de parafusos e fixadores (lista de compras à parte)

Dimensionada pelos furos das peças e pelos empilhamentos de montagem. Também entregue como documento separado (relatorio/Lista_Parafusos_Fixadores.docx).

# | Especificação (modelo) | Necess. | Comprar | Onde é usado | Furo / empilhamento | Material | R$

1 | Parafuso autoatarraxante PA 2,0 × 8 mm, cabeça panela Phillips (ponta aguda) | 8 | 20 (pacote) | Fixação dos 4 servos nos rasgos (2 por flange). Os 2 parafusos de fixação que vêm no kit de cada servo servem | Furos-piloto Ø1,7 na peça (85 % do Ø2,0: o PLA faz a rosca). Empilhamento: 2,5 mm da aba do servo + 3–4 mm de chapa | Aço carbono zincado (branco ou preto) | 6
1b | Parafuso autoatarraxante PA 2,0 × 6 mm (central do horn) + arruela M2 Ø2,2 × Ø5 × 0,3 mm | 4 | 10 | Parafuso central dos 4 horns (plataforma, braço, antebraço e dedo motriz), rosqueado no furo cego do eixo estriado do servo. A arruela apoia a cabeça na chapa | Furo passante Ø2,6 no elo. Aperto real: 2,0 mm de chapa sobre o horn + ≈ 0,8 mm do topo do horn acima do eixo = 2,8 mm; sobram 3,2 mm para o furo cego do eixo (profundidade típica 3–5 mm, varia por fabricante). ANTES DE MONTAR: rosquear o parafuso no eixo sem a peça e medir quanto entra; se entrar ≥ 5 mm, o PA 2,0 × 8 do item 1 também serve; se entrar < 3 mm, usar o parafuso do próprio kit (≈ 5 mm) — um parafuso comprido demais bate no fundo e não aperta | Aço carbono zincado | 3
2 | Micro parafuso autoatarraxante PA 1,7 × 6 mm (alternativa: 1,5 × 6), cabeça panela Phillips | 14 | 50 (kit de micro parafusos) | Prendem os horns dentro dos bolsos: 4 × plataforma (horn em cruz), 4 × braço, 4 × antebraço (horn duplo), 2 × dedo motriz (horn simples) | Furos-piloto Ø1,5 na peça, através dos furos Ø1,3–1,5 dos braços do horn (se necessário, alargar o horn com broca de 1,5 mm) | Aço zincado ou oxidado preto | 12
3 | Parafuso M3 × 25 mm, cabeça panela Phillips ou cilíndrica Allen (rosca total) | 1 | 2 | Pino/eixo da engrenagem livre da garra | Ø3,4 na palma e no dedo livre. Empilhamento: palma 4 + ressalto/engrenagem 14,8 + 2 arruelas 1,0 + porca autotravante 4,0 ≈ 24 mm | Aço inox A2 (superfície lisa = menos atrito na engrenagem) | 2
3b | Parafuso M3 × 10 mm, cabeça panela Phillips (rosqueia direto no PLA) | 4 | 6 | Amarram as duas chapas de cada elo: 2 na travessa do braço (04_braco_livre → 03_braco_motriz) e 2 na palma do antebraço (06_antebraco_livre → 05_antebraco_motriz). São eles que fecham a forquilha — sem eles as chapas abrem | Passante Ø3,4 na chapa motriz + furo-piloto Ø2,5 × 8 mm no reforço da travessa/palma. Empilhamento: chapa 4 + 6 mm de rosca no PLA | Aço zincado ou inox A2 | 2
4 | Porca autotravante M3 (nylock, DIN 985) | 1 | 2 | Trava o pino da engrenagem livre sem apertar (a engrenagem deve girar solta) | — | Aço inox A2 ou zincado | 1
5 | Arruela lisa M3 (Ø3,2 × Ø7 × 0,5 mm) | 2 | 4 | Uma entre o ressalto do dedo livre e a chapa do antebraço; outra sob a porca | — | Nylon (a do ressalto, menor atrito) e inox (a da porca) | 1
6 | Parafuso M3 × 12 mm, cabeça panela Phillips | 8 | 10 | Fixação dos 2 módulos joystick KY-023 no suporte impresso (4 por módulo) | Rasgos RADIAIS 3,4 × 11,4 no suporte (aceitam furação de 21,5 a 34,5 mm × 15,4 a 24,6 mm) + furos Ø3 da placa. Empilhamento: placa 1,6 + assento do berço 3 + chapa 4 + arruela 0,5 + porca 2,4 = 11,5 mm | Aço zincado ou inox A2 | 4
7 | Porca sextavada M3 (DIN 934) | 8 | 10 | Idem item 6 | — | Aço zincado | 2
8 | Arruela lisa M3 ampla (Ø3,2 × Ø9 × 0,8 mm) — se não houver, a comum Ø7 serve | 8 | 10 | Sob a cabeça dos parafusos dos joysticks: cobre o rasgo radial de 3,4 × 11,4 mm | — | Aço zincado | 2
9 | Parafuso M3 × 16 mm + porca M3 (ou parafuso para madeira 3,0 × 16 mm, se a base for MDF) | 4 | 4 | Fixação da base fixa na tábua/MDF de apoio — OBRIGATÓRIA: o disco Ø110 solto tomba com ≈ 15 g na garra em extensão máxima (raio de apoio 55 mm = raio do centro de massa) | 4 furos Ø3,4 no disco da base (raio 47 mm, a 45°, 135°, 225° e 315°) | Aço zincado | 2
10 | Parafuso M3 × 6 mm + espaçador de nylon M3 × 6 mm com rosca (ou M3 × 10 + porca) | 4 | 4 | Fixação do Arduino UNO na base de apoio (furos Ø3,2 da placa; normalmente 3 são acessíveis) | — | Nylon (espaçador) + aço zincado | 4

Custo total estimado dos fixadores: R$ 41.

- Cotas conferidas com os furos de cad/gerar_pecas.py: Ø1,5 e Ø1,7 = furos-piloto para parafusos autoatarraxantes (o PLA faz a rosca); Ø2,6 e Ø3,4 = furos passantes (parafuso desliza; a cabeça apoia na peça).
- Comprimento indicado é o do corpo (sob a cabeça). Se o parafuso ficar 1–2 mm mais longo não há problema; mais curto que o empilhamento indicado não fixa.
- Peças impressas com 0,2 mm tendem a fechar furos pequenos em 0,2–0,3 mm: se um autoatarraxante entrar duro, alargar com broca de 1,5 mm (furos Ø1,5) ou 1,6 mm (furos Ø1,7). Nunca forçar: o PLA racha.
- Horns de SG90 não são padronizados: os furos-piloto Ø1,5 dos bolsos seguem uma grade típica (7,5/11 mm na cruz, 8/12 mm no duplo, 8/12/15 mm no simples). Conferir com o horn comprado; se não coincidirem, furar em obra com broca de 1,5 mm usando o próprio horn como gabarito.
- Não apertar demais o pino da garra (item 3/4) nem os parafusos dos servos: aperto até encostar + 1/4 de volta.
- Os pivôs do lado LIVRE (ombro e cotovelo) não levam parafuso: são munhões Ø9 impressos na própria chapa, que giram nos mancais Ø9,4 da parede da plataforma e da chapa livre do braço. Quem segura o conjunto no eixo é o parafuso central do horn do lado motriz (item 1b) somado às travessas (item 3b) — por isso os 4 parafusos M3 × 10 são obrigatórios.
- Se um munhão entrar apertado no mancal, lixar levemente o Ø9 (lixa 220) até girar livre — não alargar o furo, que é o mancal.
- Ferramentas: chave Phillips PH0 (itens 1, 2 e 6), PH1 (itens 3, 9, 10), chave de boca/canhão 5,5 mm (porcas M3), chave Allen 2,5 mm se optar pela cabeça cilíndrica no item 3.
- A garra tem duas opções de dedos (07/08 com mandíbula plana e 10/11 com mandíbula em V) que usam exatamente os mesmos fixadores — o item 3/4/5 serve para qualquer uma das duas e a troca não muda esta lista. Quem imprimir as duas opções pode deixar um horn de servo montado em cada dedo motriz (o kit do SG90 traz vários) para trocar mais rápido.
- Onde comprar: lojas de parafusos/ferragens (M3), lojas de eletrônica/robótica e kits de micro parafusos (PA 1,7 e 2,0).

Braço Robótico 4 GDL — Sistemas Embarcados — FAESA Página (pressione F9 para atualizar)

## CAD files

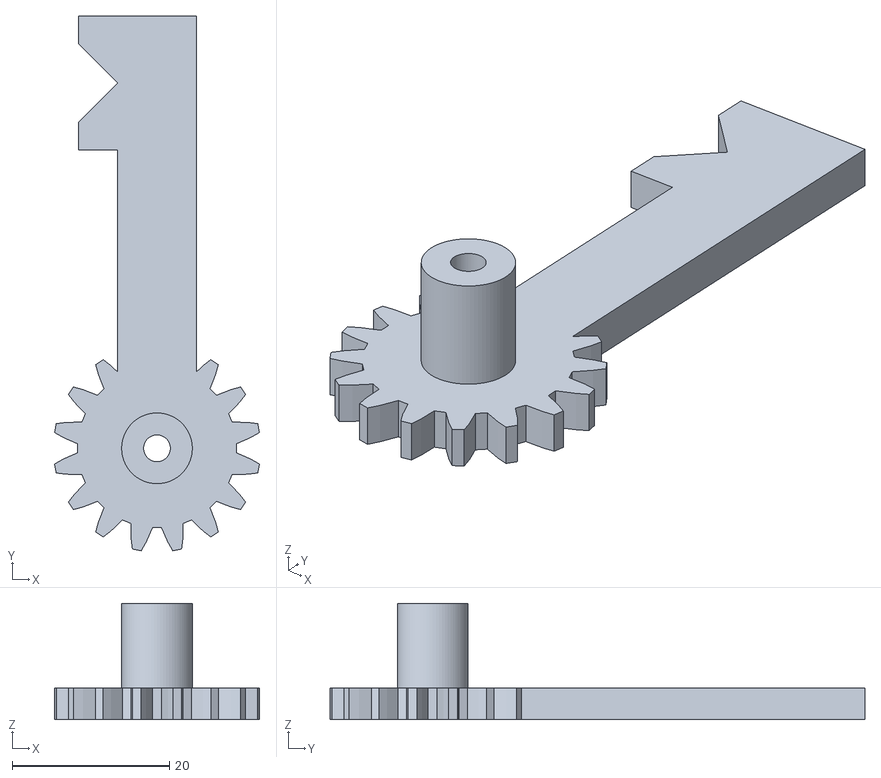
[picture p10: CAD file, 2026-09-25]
STL/11_garra_v_dedo_livre.stl
26.1 x 68.0 x 14.8

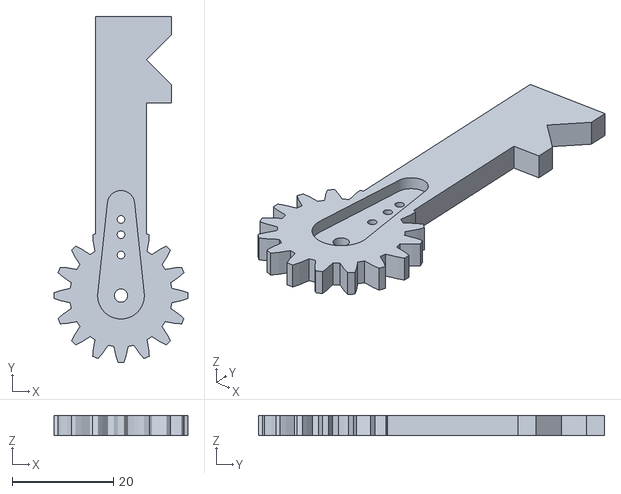
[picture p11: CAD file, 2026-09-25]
STL/10_garra_v_dedo_motriz.stl
26.4 x 68.2 x 4.00

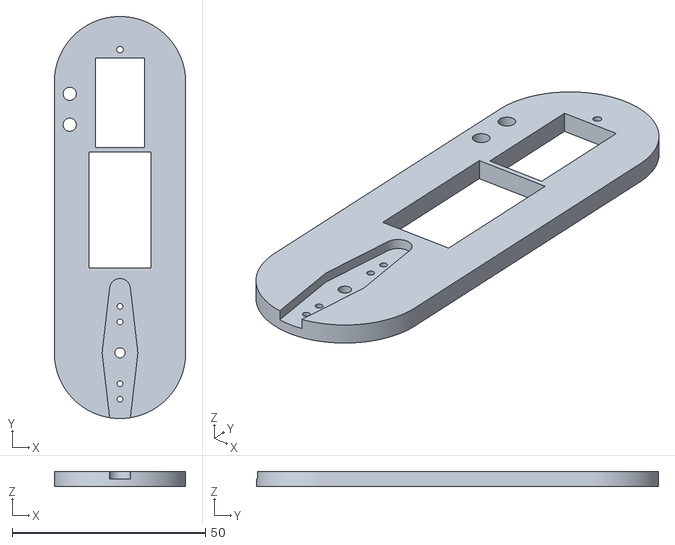
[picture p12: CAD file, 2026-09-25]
STL/03_braco_motriz.stl
34.0 x 104.0 x 4.00

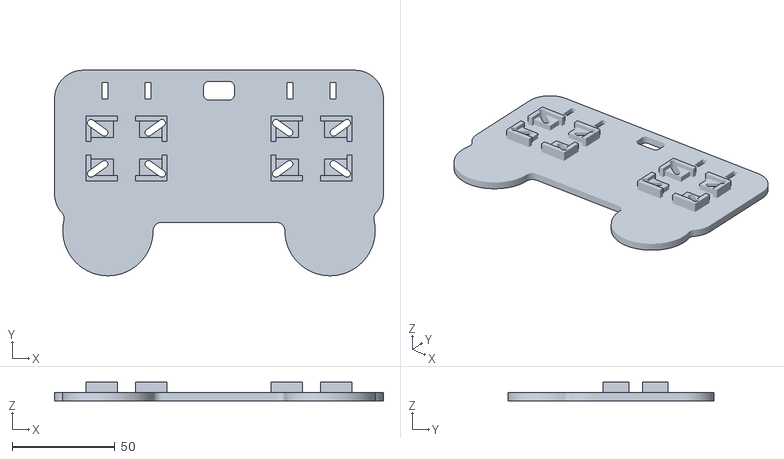
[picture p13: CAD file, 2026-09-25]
STL/09_suporte_joysticks.stl
160.0 x 100.0 x 9.20

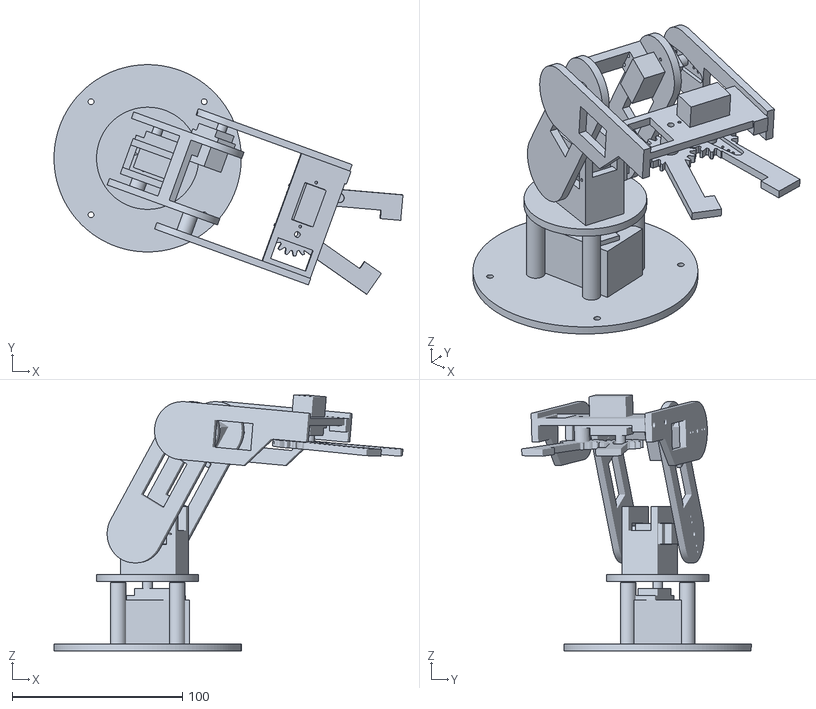
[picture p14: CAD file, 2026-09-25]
STL/montagem_completa.stl
205.0 x 134.9 x 150.4

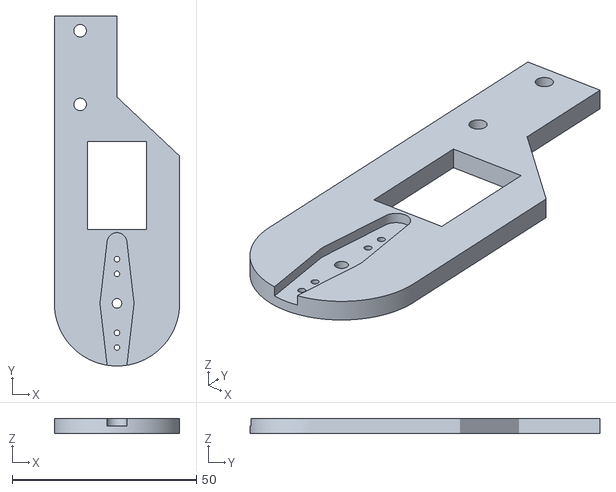
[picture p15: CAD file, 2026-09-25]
STL/05_antebraco_motriz.stl
34.0 x 95.0 x 4.00

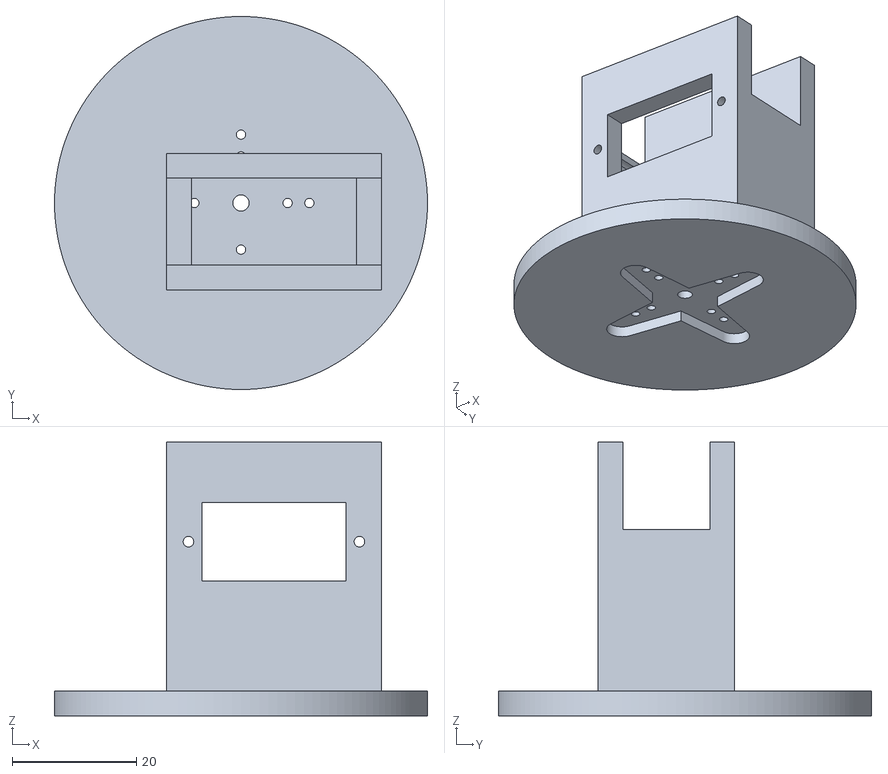
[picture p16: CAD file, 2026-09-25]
STL/02_plataforma_giratoria.stl
60.0 x 60.0 x 44.0

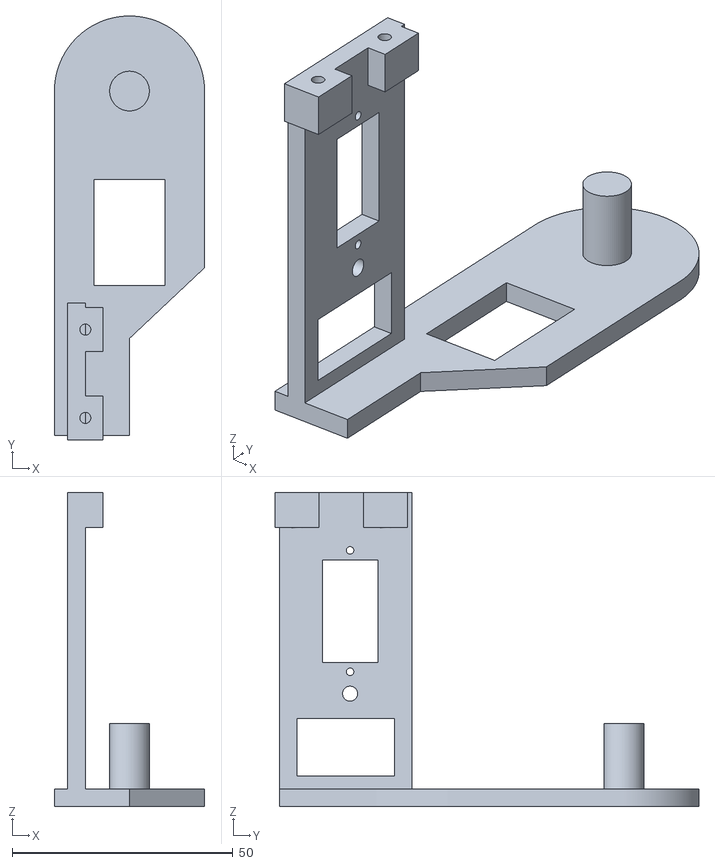
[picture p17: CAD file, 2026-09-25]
STL/06_antebraco_livre.stl
34.0 x 96.0 x 71.2

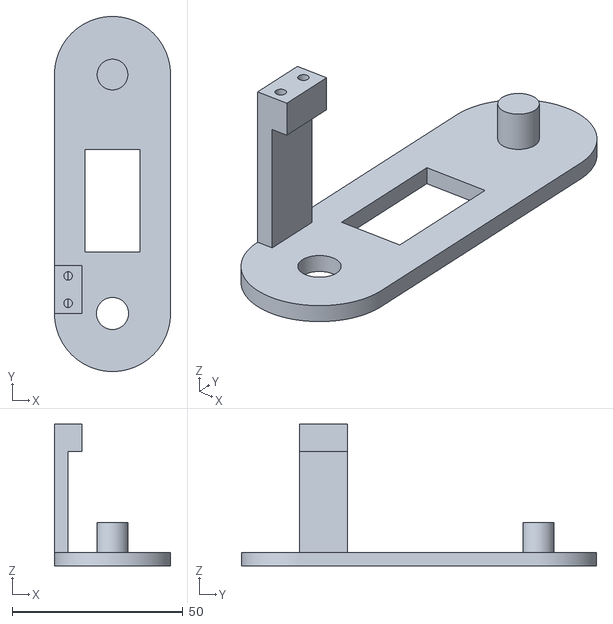
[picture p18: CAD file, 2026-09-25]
STL/04_braco_livre.stl
34.0 x 104.0 x 41.6

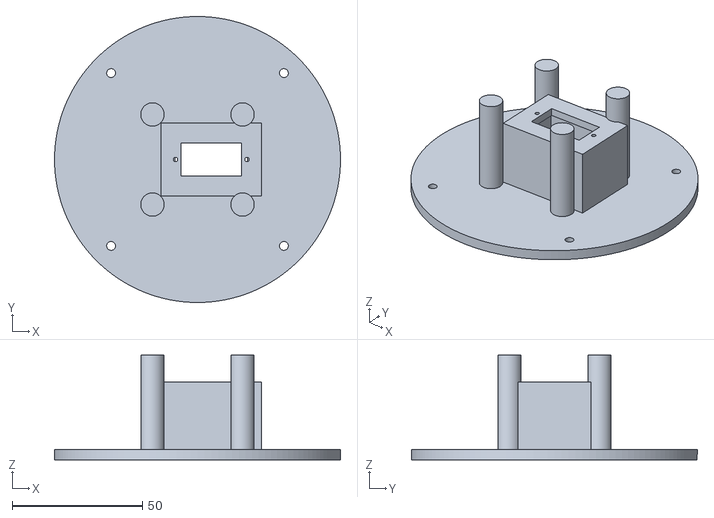
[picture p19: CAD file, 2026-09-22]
STL/01_base_fixa.stl
110.0 x 110.0 x 40.3

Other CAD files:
STL/07_garra_dedo_motriz.stl
STL/08_garra_dedo_livre.stl

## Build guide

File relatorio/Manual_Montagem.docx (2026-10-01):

BRAÇO ROBÓTICO DE 4 GRAUS DE LIBERDADE

MANUAL DE MONTAGEM

Da peça impressa ao braço calibrado — passo a passo


FAESA — Engenharia da Computação — Sistemas Embarcados — 2026/2

Aluno(a): ______________________________ Data da montagem: ____ / ____ / ______

# Como usar este manual

Leia a etapa inteira antes de executá-la. Cada etapa tem sempre a mesma estrutura: o que fazer (passos numerados, na ordem), por que assim (o motivo do projeto — ajuda a decidir na hora que algo não encaixa) e um ponto de conferência, que você só deve ultrapassar depois de conferir.

Bloco | Significado
CONFERIR | Teste de fim de etapa. Se não passar, não siga adiante — o erro só fica mais caro depois.
ATENÇÃO | Ponto onde é fácil errar e o prejuízo é retrabalho (desmontar, reimprimir uma peça).
NUNCA | Ação que queima componente ou quebra peça. Sem exceção.
DICA | Atalho ou truque de bancada que não é obrigatório.

Convenções de nome

- Motriz e livre: cada elo do braço é formado por DUAS chapas. A motriz é a que recebe o horn do servo (é ela que é puxada pelo motor); a livre é a do outro lado, que só gira apoiada num pino impresso (munhão). As duas juntas formam uma forquilha, como um garfo.
- S1, S2, S3, S4: os quatro servos — S1 base (gira o conjunto), S2 ombro, S3 cotovelo, S4 garra.
- Horn: a haste plástica branca que acompanha o servo e se encaixa no eixo estriado.
- Munhão e mancal: munhão é o pino Ø9 mm impresso na peça; mancal é o furo Ø9,4 mm que o recebe. É o par que substitui o rolamento do lado livre.

Tempo total previsto

Fase | Tempo | Observação
Impressão das peças | ≈ 6 h 40 min | 132 g de PLA no total (braço 93 g + suporte do controle 38 g)
Preparo das peças e dos servos | 40 min | Limpeza de furos e centragem dos servos em 90°
Montagem mecânica (etapas 1 a 12) | 1 h 30 min | Sem pressa, conferindo cada etapa
Montagem elétrica | 40 min | Protoboard, fonte e cabos
Firmware, calibração e testes | 1 h | Ajuste de ANG_MIN/ANG_MAX na bancada

# 1. Antes de começar

## 1.1 O que você vai montar

Um braço de 4 graus de liberdade (base, ombro, cotovelo e garra) acionado por 4 micro servos e comandado por dois joysticks analógicos. O firmware grava até 16 poses e as reproduz em sequência. Na posição de repouso (todos os servos em 90°) o braço fica com o elo superior na vertical e o antebraço na horizontal, com a garra a 165 mm de altura e 119 mm à frente do centro da base.


Figura 1 — Posição de repouso (home). É esta a pose de referência para encaixar todos os horns.

Números do conjunto montado (medidos no modelo):

Grandeza | Valor
Alcance horizontal máximo | 186 mm (ombro 165°, cotovelo 20°)
Altura máxima da garra | 249 mm
Abertura da garra (mandíbula plana) | Ø4 mm (fechada) a Ø58 mm (aberta)
Abertura da garra (mandíbula em V) | Ø10 mm a Ø53 mm, com 4 pontos de contato
Carga útil | ≈ 20 g com o braço estendido; ≈ 65 g recolhido
Massa da parte móvel | ≈ 59 g

## 1.2 Ferramentas

Ferramenta | Onde é usada | Obrigatória?
Chave Phillips PH0 (ponta fina) | Micro parafusos dos horns e parafusos dos servos | Sim
Chave Phillips PH1 | Parafusos M3 (travessas, palma, joysticks, base) | Sim
Chave de boca ou canhão 5,5 mm | Porcas M3 (pino da garra e joysticks) | Sim
Brocas 1,5 / 1,6 / 2,5 / 3,4 mm (à mão) | Repassar furos que fecharam na impressão | Sim
Lixa 220 | Ajustar o munhão Ø9 se entrar apertado | Sim
Alicate de bico e estilete | Retirar bolinhas de filamento e rebarbas | Sim
Multímetro | Conferir 5 V e continuidade antes de ligar os servos | Muito recomendável
Ferro de solda | Só se optar por soldar os extensores de cabo | Não
Paquímetro | Conferir Ø9 do munhão e Ø9,4 do mancal | Não

DICA — Uma chave PH0 de eletrônica (as de kit de celular) é o que funciona nos micro parafusos de 1,7 mm. Chave grande demais arredonda a cabeça no primeiro aperto.

## 1.3 Segurança

NUNCA — Alimentar o Arduino pelo USB e pela fonte externa no pino 5V ao mesmo tempo. As duas fontes brigam pelo mesmo barramento e o regulador do Arduino pode queimar. Escolha uma das duas.

NUNCA — Usar fonte de 6 V. Toda a análise de torque e corrente do projeto é para 5 V; a 6 V a corrente de travamento sobe para ≈ 0,85 A por servo (3,4 A no total).

ATENÇÃO — Não gire o braço com a mão enquanto os servos estiverem energizados: você está forçando a engrenagem interna contra o motor. Desligue a fonte antes de reposicionar qualquer elo.

ATENÇÃO — A garra fecha com força suficiente para machucar a ponta do dedo e para quebrar o dente da engrenagem impressa. Mantenha os dedos fora do vão ao energizar.

ATENÇÃO — A base solta TOMBA com cerca de 15 g na garra em extensão máxima. Fixar o disco na tábua (etapa 11) não é opcional.

## 1.4 Conferência do material

Peças impressas (11 arquivos STL; as peças 10 e 11 são a garra alternativa — imprima 07/08 ou 10/11):

Arquivo | Peça | Massa | Tempo | Orientação de impressão
01_base_fixa | Base fixa | 40.7 g | 122 min | Disco para baixo. Tampa da torre faz ponte de 18 mm (OK na A1; opcionalmente ativar suportes).
02_plataforma_giratoria | Plataforma giratória | 15.0 g | 45 min | Disco para baixo (bolso do horn fica na 1ª camada). Sem suportes.
03_braco_motriz | Braço — chapa motriz | 6.4 g | 19 min | Deitada, bolso do horn para cima. Sem suportes.
04_braco_livre | Braço — chapa livre | 9.5 g | 29 min | Deitada, munhão e travessa para cima (tudo vertical na mesa). Sem suportes.
05_antebraco_motriz | Antebraço — chapa motriz | 5.6 g | 17 min | Deitada, bolso do horn para cima. Sem suportes.
06_antebraco_livre | Antebraço — chapa livre + palma | 11.0 g | 33 min | Deitada, palma em pé (67 mm). Teto do rasgo de S4 faz ponte de 23 mm. Sem suportes.
07_garra_dedo_motriz | Dedo motriz da garra | 2.3 g | 7 min | Deitado, bolso do horn para cima. Sem suportes.
08_garra_dedo_livre | Dedo livre da garra | 2.9 g | 9 min | Deitado, ressalto para cima. Sem suportes.
09_suporte_joysticks | Suporte dos joysticks | 38.2 g | 115 min | Deitado, berços para cima. Sem suportes.
10_garra_v_dedo_motriz | Dedo motriz da garra em V (opção B) | 2.3 g | 7 min | Deitado, bolso do horn para cima. Sem suportes.
11_garra_v_dedo_livre | Dedo livre da garra em V (opção B) | 2.9 g | 9 min | Deitado, ressalto para cima. Sem suportes.


Figura 2 — As peças na orientação em que devem ser impressas (PLA, 0,2 mm, 15 % de preenchimento, 3 paredes, SEM suportes).

Fixadores (lista completa, com quantidade a comprar):

# | Fixador | Qtd. | Onde

1 | Parafuso autoatarraxante PA 2,0 × 8 mm, cabeça panela Phillips (ponta aguda) | 8 | Fixação dos 4 servos nos rasgos (2 por flange). Os 2 parafusos de fixação que vêm no kit
1b | Parafuso autoatarraxante PA 2,0 × 6 mm (central do horn) + arruela M2 Ø2,2 × Ø | 4 | Parafuso central dos 4 horns (plataforma, braço, antebraço e dedo motriz), rosqueado no
2 | Micro parafuso autoatarraxante PA 1,7 × 6 mm (alternativa: 1,5 × 6), cabeça pa | 14 | Prendem os horns dentro dos bolsos: 4 × plataforma (horn em cruz), 4 × braço, 4 × antebr
3 | Parafuso M3 × 25 mm, cabeça panela Phillips ou cilíndrica Allen (rosca total) | 1 | Pino/eixo da engrenagem livre da garra
3b | Parafuso M3 × 10 mm, cabeça panela Phillips (rosqueia direto no PLA) | 4 | Amarram as duas chapas de cada elo: 2 na travessa do braço (04_braco_livre → 03_braco_mo
4 | Porca autotravante M3 (nylock, DIN 985) | 1 | Trava o pino da engrenagem livre sem apertar (a engrenagem deve girar solta)
5 | Arruela lisa M3 (Ø3,2 × Ø7 × 0,5 mm) | 2 | Uma entre o ressalto do dedo livre e a chapa do antebraço; outra sob a porca
6 | Parafuso M3 × 12 mm, cabeça panela Phillips | 8 | Fixação dos 2 módulos joystick KY-023 no suporte impresso (4 por módulo)
7 | Porca sextavada M3 (DIN 934) | 8 | Idem item 6
8 | Arruela lisa M3 ampla (Ø3,2 × Ø9 × 0,8 mm) — se não houver, a comum Ø7 serve | 8 | Sob a cabeça dos parafusos dos joysticks: cobre o rasgo radial de 3,4 × 11,4 mm
9 | Parafuso M3 × 16 mm + porca M3 (ou parafuso para madeira 3,0 × 16 mm, se a bas | 4 | Fixação da base fixa na tábua/MDF de apoio — OBRIGATÓRIA: o disco Ø110 solto tomba com ≈
10 | Parafuso M3 × 6 mm + espaçador de nylon M3 × 6 mm com rosca (ou M3 × 10 + porc | 4 | Fixação do Arduino UNO na base de apoio (furos Ø3,2 da placa; normalmente 3 são acessíve

Custo estimado dos fixadores: R$ 41.

Eletrônica:

Item | Qtd. | Observação
Arduino UNO R3 | 1 | Qualquer clone serve; o firmware usa 36 % da flash
Micro servo MG90S (ou SG90) | 4 | MG90S tem engrenagem metálica e rolamento; mesmo torque a 5 V
Módulo joystick KY-023 | 2 | Com os 5 pinos (GND, +5V, VRx, VRy, SW)
Fonte chaveada 5 V / 5 A | 1 | 3 A já atende (pico normal 1,85 A); 5 A é margem
Capacitor eletrolítico 1000 µF / 16 V | 1 | No barramento de 5 V dos servos, junto à protoboard
Capacitor cerâmico 100 nF | 4 | Um em cada servo, o mais perto possível dos terminais
Protoboard 830 furos + jumpers | 1 | Só o lado direito das trilhas é usado
Extensor de servo 300 mm | 2 | Os 250 mm de fábrica não chegam de S3 e S4 ao circuito
Tábua/MDF ≈ 200 × 200 mm | 1 | Base de fixação — obrigatória

# 2. Preparo (não pule esta parte)

## 2.1 Repassar os furos das peças impressas

A impressão 3D fecha furos pequenos em 0,2 a 0,3 mm. Passe a broca à mão (sem furadeira, girando entre os dedos) em todos os furos, só para tirar a sobra de material — o furo já está no lugar certo:

Furo no desenho | Broca | Para que serve | Onde está
Ø1,5 mm | 1,5 mm | Micro parafuso PA 1,7 × 6 do horn | Fundo dos 4 bolsos de horn
Ø1,7 mm | 1,6 mm | Parafuso PA 2,0 × 8 do flange do servo | 2 furos ao lado de cada rasgo de servo
Ø2,5 mm | 2,5 mm | Furo-piloto do M3 × 10 (a rosca é feita no PLA) | Reforço da travessa e da palma
Ø2,6 mm | 2,6 mm | Parafuso central do horn (passante) | Centro de cada bolso de horn
Ø3,4 mm | 3,4 mm | M3 passante | Pino da garra, travessas, disco da base, suporte
Ø9,4 mm | — | Mancal do munhão — NÃO alargar | Parede livre da plataforma e chapa livre do braço

NUNCA — Alargar o mancal Ø9,4 para o munhão entrar mais fácil. Quem deve ser lixado é o munhão (o macho), nunca o furo: alargando o furo você cria folga que vira trepidação na ponta da garra.

DICA — Faça o teste a seco agora: encaixe cada munhão no seu mancal sem parafuso nenhum. Deve entrar com a força dos dedos e girar liso. Se raspar, lixe o munhão (lixa 220, meia volta de cada vez) até girar. Descobrir isso agora custa 2 minutos; descobrir na etapa 6 custa desmontar o braço.

## 2.2 Identificar as peças

As chapas motriz e livre de cada elo são parecidas de longe. Marque com fita crepe antes de começar — a diferença é fácil de ver de perto:

Peça | Como reconhecer
03 Braço motriz | Chapa plana de 4 mm com DOIS recortes: o bolso do horn (redondo, raso) e o rasgo retangular do servo S3
04 Braço livre | Tem um pino Ø9 saliente (munhão do ombro), um furo Ø9,4 (mancal do cotovelo) e a travessa em L
05 Antebraço motriz | Chapa plana com UM bolso de horn e nenhum rasgo de servo
06 Antebraço livre | A maior das quatro: chapa + a palma em pé (67 mm), com o rasgo do servo S4
07/10 Dedo motriz | Engrenagem com bolso de horn (para o horn simples de S4)
08/11 Dedo livre | Engrenagem com ressalto cilíndrico Ø9 × 10,8 e furo Ø3,4 passante

## 2.3 Centrar os 4 servos em 90° — a etapa mais importante do manual

O eixo do servo é estriado (≈ 21 dentes). Cada dente vale 17,1°; encaixar o horn um dente fora desloca todo o elo em até 8,6°. Por isso o horn NUNCA é encaixado com o servo desligado: primeiro o servo vai para 90° por software, depois o horn é encaixado na posição certa.

1. Monte só o mínimo elétrico: Arduino ligado ao USB, o servo em D3, alimentado pela fonte de 5 V com o GND comum (veja a seção 5). Um servo por vez basta.
2. Grave o firmware definitivo (seção 6). Ao ligar, ele já leva todas as saídas para 90° — é exatamente o que precisamos.
3. Ligue e deixe o servo atingir a posição. Não gire o eixo com a mão depois disso.
4. Repita com os quatro servos e escreva S1, S2, S3, S4 em cada um com fita.
5. Para o servo da garra (S4), mande pelo Monitor Serial o comando 's 3 75' (a 115200 bauds): a garra é montada a 75°, quase fechada, e não a 90°.

ATENÇÃO — Se você não tiver o circuito pronto ainda, pode centrar os servos com um sketch mínimo (Servo.attach + write(90)). O que não vale é encaixar o horn 'no olho'.

CONFERIR — Com o servo em 90°, o horn encaixado deve poder girar ~85° para cada lado sem bater no batente interno. Se de um lado ele trava logo, o horn está um dente fora: puxe e reencaixe.

Qual horn em qual servo:

Servo | Junta | Horn | Micro parafusos | Vai fixado em
S1 | Base (gira tudo) | Em cruz (4 braços) | 4 | 02 Plataforma giratória
S2 | Ombro | Duplo (2 braços) | 4 | 03 Braço motriz
S3 | Cotovelo | Duplo (2 braços) | 4 | 05 Antebraço motriz
S4 | Garra | Simples (1 braço) | 2 | 07 (ou 10) Dedo motriz

# 3. Montagem mecânica

Regra geral que vale para as quatro juntas: o horn é parafusado na PEÇA primeiro, com o horn fora do servo. Só depois o conjunto peça+horn é empurrado no eixo estriado e travado com o parafuso central. É muito mais fácil acertar os micro parafusos com a peça apoiada na mesa do que no ar.

DICA — Separe os fixadores em potinhos por etapa antes de começar. Micro parafuso de 1,7 mm que cai no chão não é encontrado.

## Etapa 1 — Servo S1 dentro da base fixa

Tempo | 10 min
Peças | 01_base_fixa
Fixadores | 2 × PA 2,0 × 8 (item 1)

Como fazer

6. Passe o cabo de S1 por dentro da torre, de cima para baixo, e puxe-o pelo canal que sai sob o disco.
7. Encaixe o corpo do servo no rasgo retangular do topo da torre, de cima para baixo. O rasgo é assimétrico (o eixo do servo é deslocado 5,3 mm do centro do corpo): só entra de um jeito.
8. A aba (flange) do servo deve encostar no topo da torre, com o eixo estriado para cima.
9. Aperte os 2 parafusos PA 2,0 × 8 nos furos-piloto Ø1,7, até encostar + 1/4 de volta.

Por que assim

S1 fica pendurado dentro da torre oca para baixar o centro de massa e para o cabo sair sem laço. As 4 colunas Ø9 em volta não seguram o servo: elas são o encosto da plataforma, para que o peso do braço não fique todo no estriado plástico do horn.

CONFERIR — O eixo de S1 deve estar na vertical, girar livre com a mão e o cabo deve sair pelo canal sem ficar prensado. A folga entre o topo das colunas (z = 40,3 mm) e a futura plataforma é de apenas 0,5 mm.

ATENÇÃO — Não aperte o parafuso até o fim de curso da rosca — o PLA racha. Aperto de encosto + 1/4 de volta.

## Etapa 2 — Plataforma giratória no horn de S1

Tempo | 10 min
Peças | 02_plataforma_giratoria
Fixadores | 4 × micro PA 1,7 × 6 (item 2) + 1 × PA 2,0 × 6 com arruela M2 (item 1b)

Como fazer

10. Com a plataforma de cabeça para baixo na mesa, encaixe o horn em CRUZ no bolso raso (2 mm) do lado de baixo.
11. Prenda o horn com 4 micro parafusos PA 1,7 × 6 — um em cada braço da cruz, no furo mais próximo do centro.
12. Confirme que S1 está em 90° (energizado). Empurre o conjunto plataforma+horn no eixo estriado, com a plataforma alinhada com a base (veja a Figura 1).
13. Coloque a arruela M2 no parafuso central PA 2,0 × 6 e aperte-o no furo cego do eixo do servo, pelo furo Ø2,6 da plataforma.

Por que assim

O bolso de 2 mm é quem transmite o torque (encaixe de forma); o parafuso central só impede que a peça escape do eixo. Por isso o bolso tem o formato do horn — cubo Ø9,2 mm e braços afinando até Ø5,4 mm.

CONFERIR — Gire a plataforma com a mão (servo desligado): ela deve girar sem raspar, apoiada nas 4 colunas. Energizando, S1 deve conseguir girar a plataforma de 5° a 175° sem esforço audível.

ATENÇÃO — Antes de apertar o parafuso central, rosqueie-o no eixo SEM a peça e veja quanto ele entra. O furo cego do eixo varia de 3 a 5 mm entre fabricantes: parafuso comprido demais bate no fundo e a peça continua solta.

## Etapa 3 — Servo S2 (ombro) na plataforma

Tempo | 5 min
Peças | 02_plataforma_giratoria (já montada)
Fixadores | 2 × PA 2,0 × 8 (item 1)

Como fazer

14. Identifique as duas paredes verticais da plataforma: a MOTRIZ (a mais próxima do centro) tem o rasgo do servo; a LIVRE (a mais afastada) tem só o furo redondo Ø9,4 do mancal.
15. Encaixe S2 no rasgo da parede motriz com o CORPO apontando para dentro da forquilha (para o lado da parede livre) e a aba apoiada na face externa.
16. Aperte os 2 parafusos PA 2,0 × 8.
17. Passe o cabo de S2 para baixo, junto ao cabo de S1.

Por que assim

As duas paredes não são simétricas de propósito: o corpo do SG90 avança 15,9 mm abaixo da aba, e a parede livre precisa ficar além disso (sobram 2,1 mm de folga). As duas nervuras que ligam as paredes ao disco formam um caixote — é o que impede a forquilha de abrir sob carga.

CONFERIR — Com S2 em 90°, o eixo estriado deve estar na altura do furo do mancal da parede oposta, e os dois devem estar alinhados: essa é a linha de rotação do ombro.

## Etapa 4 — Servo S3 (cotovelo) na chapa motriz do braço — bancada

Tempo | 5 min
Peças | 03_braco_motriz
Fixadores | 2 × PA 2,0 × 8 (item 1)

Como fazer

18. Com a chapa 03 na mesa, localize o rasgo do servo na ponta oposta ao bolso do horn.
19. Encaixe S3 com o corpo para o lado de DENTRO (o mesmo lado em que ficará a outra chapa do braço) e a aba apoiada na face externa da chapa.
20. Aperte os 2 parafusos PA 2,0 × 8.

Por que assim

Montar S3 agora, com a chapa solta na bancada, evita ter que trabalhar dentro do vão de 37,6 mm da forquilha depois. O empilhamento em Y do projeto é fixo: parede motriz em 4..8 mm, chapas do braço em ±18,8..22,8 mm, chapas do antebraço em ±33,6..37,6 mm.

CONFERIR — A aba do servo deve estar encostada na chapa, sem folga. O eixo de S3 aponta para o mesmo lado que o bolso do horn de S2 na outra ponta da chapa.

## Etapa 5 — Braço (chapa motriz) no horn de S2

Tempo | 10 min
Peças | 03_braco_motriz + S3
Fixadores | 4 × micro PA 1,7 × 6 (item 2) + 1 × PA 2,0 × 6 com arruela (item 1b)

Como fazer

21. Parafuse o horn DUPLO no bolso da chapa 03 com 4 micro parafusos (2 em cada braço do horn).
22. Com S2 energizado em 90°, empurre o conjunto no eixo de S2 de modo que o braço fique na VERTICAL, apontando para cima (Figura 1).
23. Coloque o parafuso central com a arruela e aperte.
24. Balance o braço de leve: ele deve acompanhar o servo sem folga angular perceptível.

Por que assim

Este é o ponto onde um dente de indexação errado se nota mais: 8,6° de erro no ombro deslocam a garra cerca de 25 mm no fim do braço. Se o braço não ficar vertical com o servo em 90°, tire e reencaixe.

CONFERIR — Braço na vertical com S2 em 90°; sem folga entre o horn e o bolso; o parafuso central apertado.

ATENÇÃO — Neste momento o braço está preso por UM lado só. Não solte o conjunto e não pendure peso até fechar a forquilha na etapa 6.

## Etapa 6 — Fechar a forquilha do braço (chapa livre + travessa)

Tempo | 10 min
Peças | 04_braco_livre
Fixadores | 2 × M3 × 10 (item 3b)

Como fazer

25. Aproxime a chapa 04 do lado oposto, com o munhão Ø9 apontando para o furo Ø9,4 da parede LIVRE da plataforma.
26. Encaixe primeiro o munhão no mancal (entra com a força dos dedos).
27. Gire a chapa até que a travessa em L encoste na chapa motriz 03, alinhando os 2 furos.
28. Aperte os 2 parafusos M3 × 10 através da chapa 03 (furo passante Ø3,4) para dentro dos furos-piloto Ø2,5 da travessa. Vá alternando entre os dois, meia volta de cada vez.
29. Mova o ombro com a mão (servo desligado): as duas chapas têm que subir e descer juntas, como uma peça só.

Por que assim

É a travessa que transforma duas chapas soltas numa forquilha. Sem ela, as chapas abrem sob carga e o munhão escapa do mancal. Com ela, cada junta trabalha em cisalhamento duplo e o esforço lateral no estriado de nylon do horn praticamente desaparece.

CONFERIR — Sem os 2 parafusos M3 × 10 o conjunto abre com a mão; com eles, não deve haver nenhum movimento relativo entre as chapas. O ombro continua girando livre.

NUNCA — Deixar de instalar os M3 × 10 'porque está justo'. Eles são o fecho estrutural do elo.

## Etapa 7 — Antebraço (chapa motriz) no horn de S3

Tempo | 10 min
Peças | 05_antebraco_motriz
Fixadores | 4 × micro PA 1,7 × 6 (item 2) + 1 × PA 2,0 × 6 com arruela (item 1b)

Como fazer

30. Parafuse o horn DUPLO no bolso da chapa 05 com 4 micro parafusos.
31. Com S3 energizado em 90°, encaixe o conjunto no eixo de S3 com o antebraço na HORIZONTAL, apontando para a frente (Figura 1).
32. Aperte o parafuso central com a arruela.

Por que assim

Com S2 e S3 em 90° o braço fica vertical e o antebraço horizontal: é a pose de home, e é a partir dela que os limites de software (40° a 140° no cotovelo) fazem sentido.

CONFERIR — Antebraço horizontal com S3 em 90°. Dobrando o cotovelo com a mão (servo desligado), nada deve bater antes de ~148°, quando a palma encosta na parede da plataforma.

## Etapa 8 — Servo S4 na palma — bancada

Tempo | 5 min
Peças | 06_antebraco_livre
Fixadores | 2 × PA 2,0 × 8 (item 1)

Como fazer

33. Apoie a peça 06 na mesa com a palma (a aba alta de 67 mm) para cima.
34. Encaixe S4 no rasgo da palma pela face INTERNA, com o corpo saindo para FORA (para longe do braço) e o eixo estriado apontando para dentro.
35. Aperte os 2 parafusos PA 2,0 × 8.

Por que assim

Os eixos das engrenagens da garra ficam ao longo do antebraço: com o antebraço na horizontal, eles ficam verticais e as mandíbulas fecham num plano horizontal — a garra pega objetos apoiados na mesa pelo lado, em vez de ter que mergulhar por cima.

CONFERIR — O corpo de S4 deve ficar totalmente fora do vão da garra; o horn, do lado de dentro, a cerca de 11 mm da face da palma.

## Etapa 9 — Garra (dois dedos) — bancada

Tempo | 15 min
Peças | 07 + 08 (mandíbula plana) ou 10 + 11 (mandíbula em V)
Fixadores | 2 × micro PA 1,7 × 6 (item 2) + 1 × M3 × 25 (item 3) + 1 porca nylock (item 4) + 2 arruelas (item 5)

Como fazer

36. Parafuse o horn SIMPLES no bolso do DEDO MOTRIZ (peça 07 ou 10) com 2 micro parafusos.
37. Mande 's 3 75' pelo Serial para levar S4 a 75° (quase fechado) e encaixe o dedo motriz no eixo, com a mandíbula apontando para a frente do antebraço. Aperte o parafuso central.
38. Monte o dedo livre: arruela de nylon entre o ressalto Ø9 e a palma, parafuso M3 × 25 passando pela palma e pelo dedo, segunda arruela e porca nylock do outro lado.
39. Antes de apertar a porca, engrene os dentes de modo que as duas mandíbulas fiquem simétricas (a mesma distância do centro). Se ficarem tortas, levante o dedo livre e gire UM dente (11,25°).
40. Aperte a nylock só até a folga sumir — o dedo livre tem que girar solto. Não é um parafuso de fixação, é um eixo.

Por que assim

As engrenagens são de 16 dentes, módulo 1,5, com o dente afinado 0,5° por flanco e addendum encurtado: a interpenetração medida é zero em 361 posições, com 0,19 mm de folga de flanco (≈1,6° de backlash). O dedo livre já sai do CAD com meia fase de dente (11,25°) para que as mandíbulas fechem paralelas.

CONFERIR — Girando o dedo motriz com a mão, o livre acompanha sem ranger e sem travar. As mandíbulas devem se encostar (sem esmagar) em S4 = 73° (valor medido) e abrir até ≈57 mm a 110°.

ATENÇÃO — Se apertar a nylock até o fim, a engrenagem prende e S4 trava — o servo esquenta e pode queimar. A porca autotravante existe justamente para poder ficar frouxa sem soltar.

DICA — Quem imprimir as duas opções de dedo (plana 07/08 e em V 10/11) pode deixar um horn montado em cada dedo motriz: a troca passa a ser só o parafuso central e o pino M3.


Figura 3 — As duas opções de dedo: mandíbula plana (07/08) e mandíbula em V, auto-centrante (10/11). Mesmo eixo, mesmo pino, mesma distância entre centros.

## Etapa 10 — Fechar a forquilha do antebraço

Tempo | 10 min
Peças | 06_antebraco_livre (com S4 e a garra)
Fixadores | 2 × M3 × 10 (item 3b)

Como fazer

41. Leve o conjunto 06 até o braço e encaixe o munhão do antebraço no mancal Ø9,4 da chapa livre do braço (04).
42. Gire até que a palma encoste na chapa motriz do antebraço (05) e os 2 furos se alinhem.
43. Aperte os 2 parafusos M3 × 10 pela chapa 05 para dentro dos furos-piloto da palma, alternando.
44. Passe os cabos de S3 e S4 por dentro das janelas das chapas, folgados o suficiente para o cotovelo percorrer toda a faixa sem esticar.

Por que assim

A palma faz o mesmo papel da travessa do braço: fecha a forquilha e ainda serve de base para o servo da garra e para o pino do dedo livre. O vão interno do antebraço é de 67,2 mm.

CONFERIR — Dobre o cotovelo devagar por toda a faixa (servo desligado) enquanto olha os cabos: nada pode ficar tracionado nem entrar na engrenagem da garra.

ATENÇÃO — Cabo preso é a falha mais comum depois da montagem: ele não quebra na hora, mas a cada ciclo puxa o conector até soltar um fio.

## Etapa 11 — Fixar a base na tábua

Tempo | 10 min
Peças | 01_base_fixa + tábua ou MDF ≈ 200 × 200 mm
Fixadores | 4 × M3 × 16 + porcas (item 9)

Como fazer

45. Marque na tábua os 4 furos do disco (raio 47 mm, a 45°, 135°, 225° e 315°).
46. Fure a tábua com broca de 3,2 mm (para M3 com porca) ou 2,5 mm (para parafuso de madeira).
47. Aparafuse o disco na tábua, sem apertar a ponto de deformar o PLA.
48. Deixe o canal do cabo livre: os cabos de S1 e S2 passam por baixo do disco.

Por que assim

Com o braço estendido, o centro de massa sai do raio de apoio do disco Ø110: bastam ≈15 g na garra para tombar o conjunto. A tábua aumenta o raio de apoio e é o que torna os testes de carga seguros.

CONFERIR — Segure a tábua e estenda o braço à frente: o conjunto não pode balançar nem levantar do apoio.

## Etapa 12 — Controle: os dois joysticks no suporte

Tempo | 15 min
Peças | 09_suporte_joysticks + 2 × KY-023
Fixadores | 8 × M3 × 12 (item 6) + 8 porcas (item 7) + 8 arruelas amplas (item 8)

Como fazer

49. Apoie cada módulo KY-023 no berço: os 4 cantos em L posicionam a placa pela borda (envelope 34,6 × 26,6 mm).
50. Alinhe os furos da placa com os rasgos radiais do suporte — eles aceitam furação de 21,5 a 34,5 mm por 15,4 a 24,6 mm, que cobre os clones de KY-023 do mercado.
51. Coloque um parafuso M3 × 12 com arruela ampla Ø9 por cima, e porca por baixo. Aperte pouco: a placa é fina.
52. Se o gimbal do seu módulo cobrir os furos de um dos lados, use só 2 parafusos na diagonal — os cantos em L já impedem a placa de escorregar.

Por que assim

Nenhum datasheet do KY-023 publica a distância entre os furos (Joy-IT, Mantech, espboards e arduinomodules só informam a placa de 34 × 26 mm), e em vários clones o gimbal cobre os furos do lado estreito. Por isso o berço não depende dessa cota: quem posiciona são os cantos, e os rasgos radiais aceitam a furação que vier.

CONFERIR — Os dois módulos firmes no berço, com os cabos saindo para o mesmo lado, e as alavancas livres para ir ao fim de curso nas quatro direções.


Figura 4 — Suporte dos joysticks: cantos em L e rasgos radiais.


Figura 5 — Vistas do conjunto montado, para conferência final da mecânica.

# 4. Montagem elétrica

O guia furo a furo da protoboard está no arquivo Circuito_Braco_Robotico.html (abra no navegador): ele mostra em qual furo entra cada perna. O que segue é o resumo e a ordem segura de energizar.

## 4.1 Pinagem

Sinal | Pino do Arduino | Observação
Servo S1 — base | D3 | Fio laranja/amarelo (sinal)
Servo S2 — ombro | D5
Servo S3 — cotovelo | D6 | Precisa de extensor de 300 mm
Servo S4 — garra | D9 | Precisa de extensor de 300 mm
Joystick 1 — VRx (base) | A0 | J1 = mão esquerda
Joystick 1 — VRy (ombro) | A1
Joystick 1 — SW | D2 | Entrada com pull-up interno
Joystick 2 — VRx (garra) | A2 | J2 = mão direita
Joystick 2 — VRy (cotovelo) | A3
Joystick 2 — SW | D4
LED de estado | D13 | LED da própria placa
+5 V dos servos | Fonte externa | NÃO sai do Arduino
+5 V dos joysticks | 5V do Arduino | Consumo desprezível
GND | Comum | Fonte e Arduino obrigatoriamente no mesmo GND

## 4.2 Ordem de montagem do circuito

53. Monte a protoboard SEM os servos e SEM o Arduino: fonte na trilha + / −, capacitor de 1000 µF entre + e − (respeitando a polaridade, a perna marcada é o negativo), e os 4 trios de furos que receberão os servos.
54. Ligue a fonte e meça com o multímetro: tem que haver 5,0 V entre a trilha + e a trilha −, e 0 V em qualquer outro lugar. Desligue.
55. Ligue o GND do Arduino à trilha − (esse é o GND comum). Sem isso, o sinal dos servos não tem referência e eles tremem sem parar.
56. Encaixe os servos: marrom/preto no −, vermelho no +, laranja/amarelo no pino de sinal correspondente.
57. Ligue os joysticks: +5V no 5V do Arduino, GND na trilha −, e os eixos nas entradas analógicas.
58. Solde (ou encaixe) um capacitor cerâmico de 100 nF entre + e − de cada servo, o mais perto possível do conector.

ATENÇÃO — Um contato de protoboard aguenta cerca de 1 A e o barramento chega a 1,85 A na reprodução com carga. Alimente a trilha + por DOIS furos afastados (ou use borne parafusado) e espalhe os servos pela trilha, em vez de enfileirá-los em furos vizinhos.

ATENÇÃO — O orçamento de queda de tensão é de 200 mV (5,0 V na fonte, 4,8 V no servo). Meio metro de fio 22 AWG com 2 A já gasta 106 mV: use 20 AWG ou mais grosso entre a fonte e a protoboard.


Figura 6 — Esquema elétrico completo.

## 4.3 Primeira energização (nesta ordem)

59. Arduino desconectado do USB, fonte desligada. Confira visualmente a polaridade de todos os conectores de servo.
60. Ligue só a fonte. Meça 5 V na trilha. Nenhum servo deve se mexer (não há sinal ainda).
61. Conecte o USB do Arduino (já com o firmware gravado). Os quatro servos vão para 90° — esse é o teste de que a alimentação e o sinal estão certos.
62. Meça a tensão na trilha + com os servos se movendo: não pode cair abaixo de 4,8 V.
63. Abra o Monitor Serial a 115200 bauds. Deve aparecer o cabeçalho do firmware com a lista de comandos.

CONFERIR — Consumo esperado: ≈0,47 A parado, 0,72 a 1,21 A movendo um ou dois eixos, 1,85 A no pior caso normal (reprodução com 4 eixos e 50 g na garra). Se a fonte esquentar muito ou a tensão cair abaixo de 4,8 V, pare e revise a fiação antes de continuar.

# 5. Firmware

64. Abra firmware/braco_robotico/braco_robotico.ino na Arduino IDE.
65. Ferramentas → Placa: Arduino UNO. Ferramentas → Porta: a porta COM do seu Arduino.
66. A biblioteca Servo já vem com a IDE; não é preciso instalar nada.
67. Carregue (Ctrl+U). O sketch ocupa 36 % da flash e 22 % da RAM.
68. Abra o Monitor Serial em 115200 bauds.

Comandos do Monitor Serial:

Comando | O que faz
p | Imprime as posições atuais das 4 juntas
s <junta> <ângulo> | Move uma junta para um ângulo (junta 0=base, 1=ombro, 2=cotovelo, 3=garra)
h | Vai para a posição de referência (POS_REF: 90° em todas)
a | Alterna a garra entre aberta e fechada
g | Grava a pose atual (máximo de 16)
r | Inicia ou para a reprodução das poses gravadas
l | Apaga todas as poses
m | Volta ao modo manual (joysticks)
j | Recalibra o centro dos joysticks (não toque nas alavancas)
e | Salva as poses na EEPROM
c | Carrega as poses da EEPROM
v<1 a 10> | Ajusta a velocidade máxima em graus por passo de 20 ms (padrão 3 = 150 °/s)

Controles no joystick:

Ação | Resultado
Joystick 1 — eixo X | Gira a base (junta 0)
Joystick 1 — eixo Y | Levanta/abaixa o ombro (junta 1)
Joystick 2 — eixo Y | Dobra/estica o cotovelo (junta 2)
Joystick 2 — eixo X | Abre/fecha a garra (junta 3)
Botão 1 (toque curto) | Grava a pose atual
Botão 1 (toque longo, 0,8 s) | Inicia ou para a reprodução; LED pisca enquanto reproduz
Botão 2 (toque curto) | Volta à posição de referência (POS_REF: 90° em todas as juntas)
Botão 2 (toque longo, 0,8 s) | Abre/fecha a garra de uma vez

O joystick funciona como VELOCIDADE, não como posição: a junta se move enquanto a alavanca estiver fora do centro, e para onde estiver quando você soltar. A zona morta é de ±60 counts (≈6 %) e a velocidade cresce com o quadrado do deslocamento, o que dá controle fino perto do centro e movimento rápido no fim de curso.

# 6. Calibração (obrigatória antes de usar)

Os limites que saem de fábrica no firmware são simétricos e conservadores porque o sentido de giro de cada servo só é conhecido depois de montado, e o encaixe estriado tem erro de indexação de até ±8,6°. Calibrar é medir, no SEU braço, até onde cada junta pode ir sem bater.

Junta | Limites de fábrica | Limite físico medido no modelo
0 — base | 5° a 175° | Sem colisão em toda a faixa
1 — ombro | 15° a 165° | Acima de 135° com o cotovelo dobrado, o antebraço desce abaixo do plano da mesa
2 — cotovelo | 40° a 140° | A palma encosta na plataforma a 148°; o braço só a 160°
3 — garra | 72° a 110° | Mandíbulas se tocam em 73° — 1° ACIMA do ANG_MIN de fábrica; abertura máxima em 110°

## 6.1 Centro dos joysticks

69. Solte as alavancas e não encoste nelas.
70. Mande o comando 'j'. O firmware lê 16 amostras de cada eixo e adota a média como centro.
71. Confirme com 'p' e mexendo de leve: nenhuma junta pode andar sozinha com a alavanca solta.

## 6.2 Sentido de cada eixo

72. Empurre cada alavanca para um lado e veja se a junta vai para o lado esperado.
73. Se algum eixo estiver invertido, troque o sinal correspondente no vetor SENTIDO[] do firmware (1 vira −1) e recarregue. A ordem do vetor é base, ombro, cotovelo, garra.

## 6.3 ANG_MIN e ANG_MAX de bancada

ATENÇÃO — Faça esta etapa com o braço preso na tábua, uma junta de cada vez, com a mão perto do cabo da fonte para desligar se algo encostar.

74. Leve tudo para a referência com 'h' (ou um toque curto no botão 2).
75. Escolha uma junta e vá aumentando o ângulo de 5 em 5 graus com 's <junta> <ângulo>', olhando o ponto de colisão mais próximo.
76. Quando faltarem uns 5° para encostar, pare e anote o valor: esse é o seu ANG_MAX daquela junta.
77. Repita no sentido contrário para achar ANG_MIN.
78. Passe os quatro pares para os vetores ANG_MIN[] e ANG_MAX[] no firmware e recarregue.
79. Repita o teste depois de recarregar: agora o firmware recusa qualquer comando fora da faixa.

DICA — Depois de calibrado, o lado esticado do cotovelo costuma chegar a 20° e o dobrado nunca passa de 145°. Se quiser eliminar de vez a pose em que o antebraço desce abaixo da mesa, limite o ombro a 135° — o custo é cerca de 50 mm de alcance.

## 6.4 Garra

80. Com 's 3 <ângulo>', feche a garra de 1 em 1 grau até as mandíbulas se encostarem SEM forçar (o servo não pode zumbir). Esse valor é o GARRA_FECHADA (referência: 74°).
81. Abra até a posição máxima útil e anote: é o GARRA_ABERTA (referência: 110°).
82. Atualize as duas constantes no firmware e recarregue.

NUNCA — Deixar a garra fechada contra um objeto rígido por muito tempo. Servo travado puxa ≈0,7 A, esquenta e é a forma mais rápida de queimar um MG90S.

## 6.5 Gravar e reproduzir uma sequência

83. No modo manual, leve o braço até a primeira pose com os joysticks.
84. Toque curto no botão 1 (ou comando 'g') para gravar. Repita até 16 poses.
85. Toque longo no botão 1 (ou 'r') para reproduzir em laço. O LED pisca enquanto reproduz.
86. Mande 'e' para salvar na EEPROM — assim a sequência sobrevive a desligar a alimentação.
87. Se mudar ANG_MIN/ANG_MAX depois de gravar, não há problema: a reprodução limita cada pose aos limites atuais antes de enviá-la aos servos.

# 7. Mapa de ângulos — o que cada grau faz em cada elo

Todas as tabelas desta seção são geradas por cad/mapa_angulos.py, que lê os limites direto do firmware (ANG_MIN, ANG_MAX, POS_REF, GARRA_FECHADA e GARRA_ABERTA) e aplica ao modelo 3D as mesmas transformações de cad/gerar_pecas.py. Os valores de altura e alcance são medidos nas malhas, não estimados.

Convenção usada no projeto

Junta | Ângulo do servo | Ângulo geométrico do modelo | Referência (90°)
0 — base | S1 = 90 + θ1 | θ1 = giro da plataforma | Braço apontando para a frente
1 — ombro | S2 = 90 + θ2 | θ2 = desvio do braço em relação à vertical | Braço na vertical
2 — cotovelo | S3 = ângulo relativo | ângulo entre o antebraço e o braço (0° = alinhados) | Antebraço perpendicular ao braço
3 — garra | S4 = 75 + α | α = giro de CADA dedo (a abertura entre as mandíbulas é 2α) | α = 15°, garra entreaberta

ATENÇÃO — Estas tabelas dizem o TAMANHO do movimento, não o sentido. Qual lado é 'para a frente' depende de como o servo foi montado e do vetor SENTIDO[] do firmware — descubra o sentido real na calibração (seção 6.2) e, se estiver invertido, é o sinal de SENTIDO[] que muda, nunca a tabela.

Eixo do ombro a 68.8 mm da mesa; o cotovelo fica 70 mm acima do ombro, medidos ao longo do braço.

## 7.1 Junta 0 — base (S1)

Faixa do firmware: 5° a 175°, referência 90°. Girar a base não muda a altura nem o alcance — só a direção para onde o braço aponta. Um grau de servo é exatamente um grau de giro da plataforma.

S1 | θ1 | Pose | Observação
5° | -85° | conjunto girado 85° para a direita | ANG_MIN
45° | -45° | conjunto girado 45° para a direita
90° | +0° | braço apontando para a frente (referência) | REFERÊNCIA
135° | +45° | conjunto girado 45° para a esquerda
175° | +85° | conjunto girado 85° para a esquerda | ANG_MAX

## 7.2 Junta 1 — ombro (S2)

Faixa do firmware: 15° a 165°, referência 90°. Medidas tiradas com o cotovelo em 90°; a altura é a do ponto mais alto do conjunto e o alcance é medido do eixo da base.

S2 | θ2 | Pose do braço | Altura máx. | Alcance | Ponto mais baixo | Nota
15° | -75° | braço 75° fora da vertical, inclinado para tras (-X) | 200 mm | 93 mm | 52 mm | ANG_MIN
45° | -45° | braço 45° fora da vertical, inclinado para tras (-X) | 201 mm | 76 mm | 52 mm
90° | +0° | braço na VERTICAL (referência) | 165 mm | 119 mm | 52 mm | REFERÊNCIA
120° | +30° | braço 30° fora da vertical, inclinado para a frente (+X) | 146 mm | 138 mm | 52 mm
135° | +45° | braço 45° fora da vertical, inclinado para a frente (+X) | 135 mm | 133 mm | 32 mm
165° | +75° | braço 75° fora da vertical, inclinado para a frente (+X) | 104 mm | 112 mm | -28 mm | ANG_MAX

ATENÇÃO — Repare na última linha: com o ombro no limite de 165° o conjunto desce a 28 mm ABAIXO do plano da mesa — é a pose em que o antebraço bate no disco da base. Ela existe dentro dos limites de fábrica; se o seu braço vai operar sobre uma mesa, limite ANG_MAX[1] a 135°.

## 7.3 Junta 2 — cotovelo (S3)

Faixa do firmware: 40° a 140°, referência 90°. Medidas tiradas com o braço na vertical (ombro em 90°). Este é o ângulo RELATIVO entre o antebraço e o braço: 0° seria o antebraço perfeitamente alinhado com o braço.

S3 | Pose do antebraço | Altura máx. | Alcance | Ponto mais baixo | Nota
20° | antebraço aberto: 70° a mais que a perpendicular (tende a alinhar com o braço em 0°) | 249 mm | 53 mm | 52 mm | alcance/altura máximos depois de calibrar
40° | antebraço aberto: 50° a mais que a perpendicular (tende a alinhar com o braço em 0°) | 228 mm | 83 mm | 52 mm | ANG_MIN de fábrica
60° | antebraço aberto: 30° a mais que a perpendicular (tende a alinhar com o braço em 0°) | 197 mm | 106 mm | 52 mm
90° | antebraço PERPENDICULAR ao braço (referência) | 165 mm | 119 mm | 52 mm | REFERÊNCIA
120° | antebraço dobrado sobre o braço: 30° além da perpendicular | 156 mm | 103 mm | 52 mm
140° | antebraço dobrado sobre o braço: 50° além da perpendicular | 156 mm | 79 mm | 46 mm | ANG_MAX de fábrica
148° | antebraço dobrado sobre o braço: 58° além da perpendicular | 156 mm | 67 mm | 36 mm | limite físico: a palma encosta na plataforma

DICA — A altura máxima (249 mm) e o alcance máximo (186 mm) só aparecem com o cotovelo em 20°, que está FORA do limite de fábrica (40°). Depois de descobrir na calibração de que lado o antebraço estica, vale abrir ANG_MIN[2] até 20° — é onde o braço ganha 100 mm de altura.

## 7.4 Junta 3 — garra (S4)

Faixa do firmware: 72° a 110°; fechada em 74°, aberta em 110°. Cada dedo gira α = S4 − 75, e os dois giram simétricos: a abertura angular entre as mandíbulas é 2α. Em 75° as mandíbulas ficam paralelas — é a pose de montagem do horn.

S4 | α (cada dedo) | Abertura angular | Nota
72° | -3° | -6° | ANG_MIN de fábrica — 1° ABAIXO do toque das mandíbulas (73°, medido por verificacao.py)
74° | -1° | -2° | GARRA_FECHADA
75° | +0° | +0° | mandíbulas paralelas — pose de montagem do horn
80° | +5° | +10°
90° | +15° | +30° | REFERÊNCIA
100° | +25° | +50°
110° | +35° | +70° | GARRA_ABERTA = ANG_MAX

Maior objeto cilíndrico que as duas mandíbulas tocam ao mesmo tempo (medido por cad/verificacao.py):

Dedos | S4 = 75° | 80° | 90° | 100° | 110°
A — mandíbula plana (07/08) | Ø4,0 mm | Ø12,6 mm | Ø29,0 mm | Ø43,6 mm | Ø57,8 mm
B — mandíbula em V (10/11) | Ø9,9 mm | Ø15,1 mm | Ø27,9 mm | Ø41,0 mm | Ø53,1 mm

ATENÇÃO — As mandíbulas das duas opções se encostam em S4 = 73° (medido em passos de 0,25°), mas o ANG_MIN[3] de fábrica é 72° — um grau ALÉM do contato. Se você levar a garra ao mínimo pelo joystick, ela fecha contra si mesma e o servo trava. Na calibração (seção 6.4), suba ANG_MIN[3] para 73 ou 74 no seu braço.

# 8. Testes de aceitação

Preencha esta tabela na entrega — ela é a evidência de que o protótipo funciona.

# | Teste | Critério | OK?

1 | Referência ao ligar | Os 4 servos vão para 90° e o braço fica como a Figura 1 | ☐
1b | Botão de retorno | Um toque curto no botão do joystick 2, de qualquer pose, traz os 4 servos de volta à Figura 1 | ☐
2 | Faixa de cada junta | Cada junta percorre ANG_MIN..ANG_MAX sem encostar em nada | ☐
3 | Alcance horizontal | ≈186 mm do centro da base com o braço estendido | ☐
4 | Altura máxima | ≈249 mm | ☐
5 | Garra — objeto prismático | Segura uma borracha ou caixinha sem escorregar | ☐
6 | Garra — objeto cilíndrico | Segura uma caneta em pé (use os dedos em V se escorregar) | ☐
7 | Carga útil | Levanta ≈20 g com o braço estendido sem o ombro ceder | ☐
8 | Gravar e reproduzir | 4 poses gravadas reproduzem em laço sem travar | ☐
9 | Persistência | Depois de desligar e religar, 'c' recupera as poses | ☐
10 | Tensão sob carga | A trilha de 5 V não cai abaixo de 4,8 V na reprodução | ☐
11 | Estabilidade | Com a tábua fixada, o conjunto não tomba em nenhuma pose | ☐
12 | Temperatura | Depois de 5 min de reprodução, nenhum servo está quente ao toque | ☐


Figura 7 — Pose de captura: a garra fecha num plano horizontal, pegando o objeto pelo lado.

# 9. Solução de problemas

Sintoma | Causa provável | O que fazer
Todos os servos tremem sem parar | GND da fonte não está ligado ao GND do Arduino | Ligar o GND comum. É a falha número um.
Um servo treme sozinho, parado | Ruído no sinal ou queda de tensão momentânea | Capacitor de 100 nF junto ao servo; encurtar o cabo de sinal; conferir 4,8 V mínimos.
O braço cai quando desligo | Comportamento normal: sem energia não há torque | Guardar o braço recolhido; apoiar antes de desligar.
Uma junta anda sozinha com o joystick solto | Centro do joystick desatualizado | Comando 'j' com as alavancas soltas.
A junta vai para o lado errado | Sentido do servo invertido na montagem | Trocar 1 por −1 na posição correspondente de SENTIDO[].
O elo ficou torto com o servo em 90° | Horn encaixado um dente fora (17,1° por dente) | Soltar o parafuso central, puxar o horn e reencaixar um dente para o lado.
A garra não fecha de todo / esmaga | GARRA_FECHADA fora do ponto de toque real | Refazer a seção 6.4 de 1 em 1 grau.
Um dedo da garra pula dente | Porca nylock frouxa demais ou dente com rebarba | Apertar a nylock até tirar a folga axial (sem prender) e limpar o dente com estilete.
A garra trava e o servo zumbe | Nylock apertada demais, prendendo a engrenagem | Afrouxar até o dedo livre girar solto. Desligar imediatamente enquanto ajusta.
As chapas do elo abrem sob carga | Faltam os parafusos M3 × 10 da travessa/palma | Instalar os 4 parafusos do item 3b.
O munhão sai do mancal | Forquilha aberta (mesma causa acima) ou mancal alargado | Fechar a forquilha; se o furo foi alargado, reimprimir a peça.
Micro parafuso gira sem prender | Furo-piloto Ø1,5 alargado demais ou rosca espanada no PLA | Usar o furo vizinho do horn (a grade tem 2 ou 3 furos por braço).
A reprodução congela numa pose | Pose gravada fora dos limites atuais | Já tratado no firmware (a pose é limitada); se persistir, apagar com 'l' e regravar.
O Arduino reinicia sozinho | Fonte ligada no pino 5V junto com o USB, ou queda de tensão | Usar uma alimentação só; reforçar o fio da fonte para 20 AWG.
A base tomba | Braço sem a tábua de fixação | Etapa 11 — não é opcional.
Furos ficaram todos apertados | Compensação de furo da impressora | Ativar 'X-Y hole compensation' de 0,1 mm no fatiador e reimprimir.

# 10. Manutenção

- Reaperte os 4 parafusos M3 × 10 e os parafusos centrais dos horns depois da primeira hora de uso: o PLA acomoda e aparece folga.
- Guarde o braço na pose de home ou recolhido — deixar o braço estendido por dias com o servo desligado deforma nada, mas facilita esbarrões.
- Se aparecer folga angular numa junta, o suspeito é o bolso do horn (desgaste do encaixe de forma) — é a peça que se reimprime, não o servo.
- Não lubrifique as engrenagens impressas: graxa atrai pó de PLA e vira pasta abrasiva.
- Antes de qualquer alteração de cota, lembre que as peças vêm de cad/gerar_pecas.py — altere lá e regere, nunca edite o STL.

Fim do manual. Em caso de dúvida sobre uma cota, o desenho vale mais que o texto: cad/gerar_pecas.py é a fonte de todas as dimensões citadas aqui.

Manual de Montagem — Braço Robótico 4 GDL — FAESA Página (F9 atualiza)

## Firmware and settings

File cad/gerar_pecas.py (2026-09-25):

# -*- coding: utf-8 -*-
"""
gerar_pecas.py — Modelagem paramétrica (CSG) das peças do braço robótico de 4 GDL
(base giratória, ombro, cotovelo e garra) acionado por 4 micro-servos SG90/MG90S.

Arquitetura (revisão 2026-09-24):
  * Estrutura em FORQUILHA: cada elo tem duas chapas laterais (motriz + livre) simétricas
    em relação ao plano de rotação da base (y = 0). O servo fica entre elas, com o flange
    na chapa motriz; o lado livre gira num munhão Ø9 impresso na própria chapa.
  * GARRA NA PALMA: as engrenagens têm eixo ao longo de X do antebraço, ou seja, ficam
    VERTICAIS quando o antebraço está na horizontal — as mandíbulas fecham num plano
    horizontal (captura lateral de objetos apoiados na mesa).

Gera:
  STL/<peca>.stl            — uma peça por arquivo, já na orientação de impressão (Bambu Lab A1)
  STL/montagem_completa.stl — modelo montado (peças + servos) para visualização
  imagens/montagem_*.png    — vistas do protótipo montado
  cad/pecas_info.json       — dimensões, volume e estimativas de massa/tempo por peça

Uso:  python cad/gerar_pecas.py
Req.: pip install trimesh manifold3d shapely numpy matplotlib
"""
import os, json, math
import numpy as np
import trimesh
from trimesh.creation import box as _box, cylinder as _cyl, extrude_polygon
from trimesh.transformations import rotation_matrix, translation_matrix
from shapely.geometry import Polygon, Point, LineString
from shapely.ops import unary_union

RAIZ = os.path.dirname(os.path.dirname(os.path.abspath(__file__)))
DIR_STL = os.path.join(RAIZ, "STL")
DIR_IMG = os.path.join(RAIZ, "imagens")
os.makedirs(DIR_STL, exist_ok=True)
os.makedirs(DIR_IMG, exist_ok=True)

# ------------------------------------------------------------------ servo SG90 / MG90S (mm)
SV_L, SV_W        = 22.8, 12.2      # corpo (comprimento x largura)
SV_RASGO_L, SV_RASGO_W = 23.2, 12.6 # rasgo na peça: folga de 0,2 mm por lado
SV_DESLOC_EIXO    = 5.3             # eixo de saída deslocado 5,3 mm do centro do corpo
SV_FURO_X         = 13.75           # furos do flange a ±13,75 do centro do corpo (27,5 entre centros)
SV_FURO_D         = 1.7             # furo-piloto do flange: 85 % do Ø2,0 do PA (1,9 = 95 %, nao cortava rosca)
SV_ABAIXO         = 15.9            # corpo abaixo da face de apoio do flange
SV_FLANGE_T       = 2.5
SV_ACIMA          = 4.3             # corpo acima do flange
SV_EIXO           = 5.5             # ressalto + eixo estriado acima do corpo
HORN_TOPO   = SV_FLANGE_T + SV_ACIMA + SV_EIXO + 0.5   # 12,8: face superior do horn
BOLSO_HORN  = 2.0                                     # profundidade do bolso do horn na peça
GAP_ELO     = HORN_TOPO - BOLSO_HORN                  # 10,8: face interna do elo -> face de apoio do servo
ESP         = 4.0                                     # espessura padrão das chapas
GEAR_N, GEAR_M = 16, 1.5                              # engrenagens da garra: 16 dentes, módulo 1,5 (Ø primitivo 24)

# ------------------------------------------------------------------ forquilha (simetria em y = 0)
CX       = SV_DESLOC_EIXO
Y_PAR_A  = (4.0, 8.0)        # parede motriz da plataforma (flange de S2 apoia em y = 8)
Y_PAR_B  = (-14.0, -10.0)    # parede livre: corpo de S2 termina em y = -7,9 -> 2,1 mm de folga
Y_ELO1   = Y_PAR_A[1] + GAP_ELO                 # 18,8: face interna das chapas do braço (|y|)
Y_ELO2   = Y_ELO1 + ESP + GAP_ELO               # 33,6: face interna das chapas do antebraço (|y|)
MUNHAO_D     = 9.0           # munhão impresso do lado livre (mesmo Ø do espaçador do dedo livre)
MUNHAO_FOLGA = 0.4           # furo do mancal: Ø9,4
PIL_M3       = 2.5           # furo-piloto para M3 autoatarraxante em PLA (83 % do Ø nominal)
PASS_M3      = 3.4           # furo passante M3
Z_GARRA  = 62.0              # eixos das engrenagens, medidos do cotovelo
Y_GARRA  = GEAR_M * GEAR_N / 2                  # 12,0: ±12 -> 24 mm entre centros (= módulo x dentes)
PALMA_X  = (-14.0, -10.0)    # chapa da palma (normal X); face de apoio de S4 em x = -10
PALMA_Z  = (48.0, 78.0)

# ------------------------------------------------------------------ utilidades CSG
def box(x0, x1, y0, y1, z0, z1):
    m = _box(extents=[x1 - x0, y1 - y0, z1 - z0])
    m.apply_translation([(x0 + x1) / 2, (y0 + y1) / 2, (z0 + z1) / 2])
    return m

def cyl(r, h, c=(0, 0, 0), eixo='z', n=72):
    m = _cyl(radius=r, height=h, sections=n)
    if eixo == 'x':
        m.apply_transform(rotation_matrix(math.pi / 2, [0, 1, 0]))
    elif eixo == 'y':
        m.apply_transform(rotation_matrix(math.pi / 2, [1, 0, 0]))
    m.apply_translation(c)
    return m

def uniao(*ms):
    return trimesh.boolean.union(list(ms), engine='manifold')

def subtrai(a, *ms):
    return trimesh.boolean.difference([a] + list(ms), engine='manifold')

def frame(origem, eixo_z, eixo_x):
    """Matriz 4x4 que leva o sistema canônico (x, y, z) para (eixo_x, z×x, eixo_z) em 'origem'."""
    z = np.asarray(eixo_z, float); z /= np.linalg.norm(z)
    x = np.asarray(eixo_x, float); x /= np.linalg.norm(x)
    y = np.cross(z, x)
    M = np.eye(4); M[:3, 0] = x; M[:3, 1] = y; M[:3, 2] = z; M[:3, 3] = origem
    return M

def coloca(m, origem, eixo_z, eixo_x):
    m = m.copy(); m.apply_transform(frame(origem, eixo_z, eixo_x)); return m

def Rx(g): return rotation_matrix(math.radians(g), [1, 0, 0])
def Ry(g): return rotation_matrix(math.radians(g), [0, 1, 0])
def Rz(g): return rotation_matrix(math.radians(g), [0, 0, 1])
def T(x, y, z): return translation_matrix([x, y, z])

def chapa(poligono_xz, espessura=ESP):
    """Extruda um perfil 2D dado em (x, z) numa chapa que ocupa y = -espessura .. 0.
    (Rx(+90) leva (x, y, z) -> (x, -z, y): o perfil vai para o plano XZ e a espessura para -y.)"""
    m = extrude_polygon(poligono_xz, espessura)
    m.apply_transform(Rx(90))
    return m

# ------------------------------------------------------------------ "cortadores" reutilizáveis
# Sistema canônico do servo: eixo de saída = origem apontando +z; corpo estende-se ao longo de +x
# (centro do corpo em x = +5,3); face de apoio do flange em z = 0.
def corte_servo():
    """Rasgo passante do corpo do servo + 2 furos-piloto do flange."""
    rasgo = box(CX - SV_RASGO_L / 2, CX + SV_RASGO_L / 2, -SV_RASGO_W / 2, SV_RASGO_W / 2, -25, 25)
    f1 = cyl(SV_FURO_D / 2, 50, (CX + SV_FURO_X, 0, 0))
    f2 = cyl(SV_FURO_D / 2, 50, (CX - SV_FURO_X, 0, 0))
    return uniao(rasgo, f1, f2)

HORN_R_CUBO  = 4.6      # cubo do horn Ø8 + 0,3 mm de folga por lado
HORN_R_PONTA = 2.7      # meia-largura na ponta do braço (5,4 mm, como o rasgo reto da versão anterior)
HORN_CORTE_H = 8.2      # altura dos cortadores de furo: cobre os 4 mm de chapa nas três orientações, e só
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

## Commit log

2026-09-22 Braço robótico 4 GDL — projeto completo (CAD, firmware, relatório, guia de ligações)
    Entregas da disciplina Sistemas Embarcados (FAESA 2026/2):
    - cad/: gerador paramétrico das 7 peças (trimesh) e do esquema elétrico
    - STL/: peças na orientação de impressão + montagem completa
    - firmware/: Arduino UNO, 4 servos, 2 joysticks KY-023, gravar/reproduzir
    - relatorio/: geradores e .docx (relatório + lista de fixadores)
    - Circuito_Braco_Robotico.html: guia de ligações furo a furo
    - imagens/: renders e esquema
    [01_base_fixa.stl, 02_plataforma_giratoria.stl, 03_braco.stl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]
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2026-09-25 Estrutura em forquilha, garra com captura horizontal e berço dos joysticks
    Mecânica (cad/gerar_pecas.py):
    - Cada elo passa a ter DUAS chapas laterais simétricas em relação ao plano de
    rotação da base (03/04 braço, 05/06 antebraço). O servo trabalha entre elas
    (flange na chapa motriz) e o lado livre gira num munhão Ø9 impresso que entra
    num mancal Ø9,4 — cisalhamento duplo, sem esforço lateral no horn, centro de
    massa sobre o eixo da base. Travessa (braço) e palma (antebraço) fecham a
    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
    [02_plataforma_giratoria.stl, 03_braco.stl, 03_braco_motriz.stl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]
2026-09-25 Segunda opção de garra: dedos com mandíbula em V (auto-centrante)
    Peças 10 e 11: mesmo corpo de engrenagem, mesmo bolso de horn, mesmo pino M3 e
    mesma distância entre centros dos dedos 07/08 — é troca direta, sem mexer no
    antebraço, na palma, no servo nem no firmware.
    - Mandíbula de 10 x 17 mm com entalhe em V de ~95° (apex 5 mm dentro da face,
    abertura 11 mm). Contato em 4 pontos: cilindros e esferas se auto-centram e
    não rolam. Como a garra fecha no plano horizontal, o sulco do V fica vertical
    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
    [10_garra_v_dedo_motriz.stl, 11_garra_v_dedo_livre.stl]
2026-09-26 Dimensionamento da fonte: analise de corrente e fonte 5 V / 5 A
    Novo cad/verificacao_eletrica.py: modelo de motor CC alimentado pelas
    fracoes de torque de verificacao.py.
    - datasheet TowerPro do MG90S nao publica corrente nenhuma; valores de
    medicao de terceiros a 5 V (10 mA / 120-250 mA / 700 mA travado)
    - pior caso de operacao 1,85 A; falha com os 4 travados 2,70 A;
    pico de inversao de sentido ~2,6 A no barramento
    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
2026-09-27 Modelo equivalente do barramento de 5 V para simulacao
    O EveryCircuit (e simuladores analogicos em geral) nao tem Arduino,
    servo nem joystick na biblioteca - so fontes, resistivos, reativos,
    chaves, amp-ops, diodos, transistores, logica, latches, CIs e medidores.
    O esquema de ligacao nao pode ser digitado la; o que se simula e o
    subsistema de potencia.
    Novo cad/gerar_esquema_everycircuit.py -> imagens/esquema_everycircuit.png:
    - modelo A: 4 componentes + terra (cabe no limite de 5 do plano gratuito)
    - modelo B: fonte, Rs, Lf, Rf, amperimetro, C1 com ESR, voltimetro e os
    4 servos como chave + resistor (R = 5 V / I da secao 8.1)
    - o script tambem resolve o CC e o transitorio e imprime os va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
    [gerar_relatorio.py]
2026-09-29 Manual de montagem passo a passo (relatorio/Manual_Montagem.docx)
    Documento de bancada, gerado por relatorio/gerar_manual_montagem.py a partir das
    mesmas fontes do relatório (cotas de cad/gerar_pecas.py, fixadores de
    relatorio/parafusos.py, ângulos e comandos do firmware).
    - 12 etapas de montagem com o mesmo bloco: como fazer (passos numerados), por que
    assim (o motivo do projeto) e um ponto de CONFERIR que fecha a etapa.
    - Preparo: repassar cada furo com a broca certa (Ø1,5/1,6/2,5/2,6/3,4) e teste a
    seco do munhão no mancal antes de montar qualquer coisa.
    - Regra dos horns: parafusar o horn na peça fora do servo, com o servo já em 90°
    (garra 75°) — o estriado de ~21 dentes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
    [gerar_manual_montagem.py]
2026-09-29 Mapa de angulos por junta (cad/mapa_angulos.py) e secao 7 do manual
    cad/mapa_angulos.py lê ANG_MIN/ANG_MAX/ANG_HOME/GARRA_* direto do .ino, aplica as
    mesmas transformações de gerar_pecas.poses() e mede altura, alcance e ponto mais
    baixo nas malhas. Grava cad/mapa_angulos.json, consumido pelo manual.
    Convenção (a mesma de gerar_pecas.montagem):
    S1 = 90 + th1 (th1 = giro da plataforma)
    S2 = 90 + th2 (th2 = 0 -> braço na vertical, + para +X)
    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
2026-10-01 Botao do joystick 2 volta o braco para a posicao de referencia
    ANG_HOME passa a POS_REF (posicao de referencia), com a justificativa de
    cada angulo documentada no .ino: base 90 (centro do curso), ombro 90
    (braco vertical, torque minimo), cotovelo 90 (antebraco perpendicular,
    longe dos 148 graus de colisao) e garra 90 (meio curso, nao aperta o
    objeto nem fecha contra si mesma).
    Botoes do joystick 2 invertidos: toque CURTO = volta a referencia (era
    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
2026-10-20 Revisao do firmware: compila no UNO R4, protege a calibracao dos joysticks e adiciona diagnostico
    - PIN_LED -> PIN_LED_STATUS: no UNO R4 PIN_LED e macro da placa e o sketch nao compilava
    - calibracao confere cada eixo (centro 512 +/- 150, ruido <= 40); eixo reprovado e desativado
    com aviso, em vez de a junta correr sozinha ate o limite quando o braco liga com a alavanca inclinada
    - servos escritos antes do attach e 0,5 s de espera antes de calibrar
    - debounce por estabilidade, LED sem delay(), leitura serial sem String e sem bloqueio
    (aceita qualquer fim de linha), comandos 'd' (diagnostico) e '?', ajuda impressa na partida
    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
2026-10-29 Sketch de testes de bancada teste_braco_29.10
    Programa auxiliar de bancada (nao e o firmware do braco): exercita os 4
    servos e os 2 joysticks KY-023 antes e durante a montagem, na mesma
    ligacao e com a mesma escala de pulso do firmware (600..2400 us).
    Ao ligar nenhum servo recebe pulso. Dois caminhos de teste:
    monitor serial (115200 bps) para mover um servo por vez, com ida a um
    angulo, passo de 1 grau, teste automatico 90 -> min -> max -> 90,
    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
2026-10-29 Documenta o sketch de testes no CLAUDE.md
    Nova secao "Sketch de testes de bancada": para que serve, por que nenhum
    servo recebe pulso ao ligar, os dois caminhos de teste (serial e
    joystick), os comandos limite/limites que geram as linhas de
    ANG_MIN/ANG_MAX da calibracao pendente e onde ficam as copias de
    desenvolvimento em "Ambiente de testes" (fora do git).
2026-10-30 Permite operar o braco com uma junta desligada (servo S1 com defeito)
    JUNTA_LIGADA[] marca quais juntas tem servo em uso. A junta desligada nao
    recebe attach() nem pulso (pino em repouso), seu eixo de joystick fica
    inerte, a calibracao nao a reprova e os comandos que a moveriam avisam.
    Sai com a base (S1/D3/A0) desligada; as outras tres juntas funcionam
    normalmente. Pinos, limites, POS_REF e formato da EEPROM inalterados.
2026-10-31 Base de apoio em acrilico com painel do medidor DSN-VC288
    Chapa 300x260x6 mm de PMMA cortada a laser (nao furada a mao: acrilico
    trinca na broca). cad/base_suporte.py gera o DXF R12 e o SVG de corte,
    o desenho cotado e a verificacao.
    Decisoes que o calculo impos:
    - Zona proibida de +-85 graus e raio 186 mm a frente do eixo de S1: a
    garra desce 28 mm abaixo do plano da base nas poses extremas. Toda a
    eletronica fica atras da linha do eixo, onde S1 nao alcanca.
    - Tombamento resolvido: o centro de massa do conjunto fica 31 a 53 mm
    ATRAS do eixo com 0 a 50 g na garra. A tabua de fixacao obrigatoria
    da revisao de viabilidade passa a ser dispensavel.
    - Chapa elevada 15 mm: o cabo de S1 sa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
2026-11-13 Plataforma giratoria para servo MG996R no ombro (peca 12) + carga maxima
    Peca NOVA (nao substitui 02_plataforma_giratoria, que continua para MG90S):
    STL/12_plataforma_giratoria_mg996r.stl, gerada por cad/plataforma_mg996r.py.
    O MG996R desce 26,5 mm abaixo das abas (MG90S: 15,9), o que empurra a parede
    livre da forquilha e, por simetria, as chapas do braco: Y_ELO1 vai de 18,80
    para 26,75 mm. Mantidos o bolso do horn de S1, o eixo do ombro em z = 28 (a
    cinematica continua valendo), o mancal O9,4 e a folga das colunas da base.
    Placa virou retangulo arredondado para apoiar a parede livre, que saiu de
    y = -14 para -25. Fixacao por 4 x M3 a 49,5 mm entre centros. 11 verificacoes
    geometricas no pr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
